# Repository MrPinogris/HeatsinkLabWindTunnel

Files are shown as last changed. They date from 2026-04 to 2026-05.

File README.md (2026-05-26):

# HeatsinkLab Wind Tunnel

ESP32-S3 based heatsink thermal characterisation platform. A ceramic heater drives the heatsink under test to a series of set-point temperatures while a controlled fan provides forced convection through the wind tunnel. All sensor data streams to a browser-based GUI; results are saved automatically as a CSV.

---

## System Architecture

```
┌──────────────────────────────────┐
│  Firmware (C++ / ESP32-S3)       │  src/  — stable, treat as black box
│  · PID heater + fan control      │
│  · MAX6675 thermocouple (SPI)    │
│  · INA226 power monitor (I²C)    │
│  · SDP510 diff. pressure (I²C)   │
│  · EZO-HUM humidity probe (I²C)  │
│  · Serial command interface      │
└────────────┬─────────────────────┘
             │ USB Serial 115 200 baud
┌────────────▼─────────────────────┐
│  Backend  (Python / FastAPI)     │  tools/web_gui/server.py
│  · WebSocket server :8765        │
│  · Telemetry parser              │
│  · CSV logger                    │
│  · Virtual MCU simulator         │
└────────────┬─────────────────────┘
             │ WebSocket
┌────────────▼─────────────────────┐
│  Frontend (HTML / JS / CSS)      │  tools/web_gui/static/index.html
│  · Chart.js real-time graphs     │
│  · PID tuning controls           │
│  · Tester workflow (automated)   │
│  · CSV export                    │
└──────────────────────────────────┘
```

---

## Hardware

### Component Summary

| Component | Part | Interface | I²C Address |
|---|---|---|---|
| MCU | ESP32-S3 DevKit-C1 | — | — |
| Temperature sensor | MAX6675 thermocouple module | SPI | — |
| Power monitor | INA226 (A0 → VCC) | I²C | 0x41 |
| Differential pressure | Sensirion SDP510 | I²C | 0x40 |
| Humidity probe | EZO-HUM (Atlas Scientific) | I²C | 0x6F |
| Heater switch | MOSFET module (PWM gate) | GPIO 4 | — |
| Fan PWM | MOSFET / driver module | GPIO 5 | — |
| Fan power cut-off | MOSFET module (digital gate) | GPIO 10 | — |

### ESP32-S3 Pin Assignments

| GPIO | Function | Notes |
|---|---|---|
| 4 | Heater MOSFET gate | PWM 500 Hz, 8-bit (0–255) |
| 5 | Fan PWM signal | PWM 500 Hz, 8-bit |
| 10 | Fan power MOSFET gate | HIGH = powered, LOW = fully off |
| 11 | MAX6675 SO (MISO) | SPI |
| 12 | MAX6675 CS | SPI |
| 13 | MAX6675 SCK | SPI |
| 15 | I²C SDA | Shared bus: INA226, SDP510, EZO-HUM |
| 16 | I²C SCL | Shared bus |

---

## Wiring

### Power Distribution

```
12 V Lab PSU (+) ─────┬──────────────────── Heater MOSFET IN+
                      └──────────────────── Fan MOSFET IN+
12 V Lab PSU (−) ─────┬──────────────────── Heater MOSFET IN−
                      ├──────────────────── Fan MOSFET IN−
                      └──────────────────── ESP32 GND (common)
```

### Heater Power Path

```
12 V (+) → Heater MOSFET IN+
           Heater MOSFET OUT+ → Heater element (+)
           Heater element (−) → INA226 IN+
                                INA226 IN−  → Heater MOSFET OUT−
12 V (−) → Heater MOSFET IN−  (common GND)

ESP GPIO 4  → Heater MOSFET signal
ESP GND     → Heater MOSFET signal GND
```

INA226 shunt is wired in series with the heater so it measures heater current directly.

### Fan Power Path

```
12 V (+) → Fan MOSFET (power cut-off) IN+
           Fan MOSFET OUT+ → Fan (+) / PWM driver IN+
12 V (−) → Fan MOSFET IN−  (common GND)

ESP GPIO 5  → Fan PWM signal
ESP GPIO 10 → Fan power MOSFET gate  (HIGH = fan enabled, LOW = fully off)
ESP GND     → Fan MOSFET signal GND
```

### MAX6675 Thermocouple (SPI)

| MAX6675 Pin | Connects to |
|---|---|
| VCC | ESP32 3.3 V |
| GND | ESP32 GND |
| SCK | GPIO 13 |
| CS  | GPIO 12 |
| SO  | GPIO 11 |

### INA226 Power Monitor (I²C, 0x41)

| INA226 Pin | Connects to |
|---|---|
| VCC | ESP32 3.3 V |
| GND | ESP32 GND |
| SDA | GPIO 15 |
| SCL | GPIO 16 |
| A0  | 3.3 V (sets address to 0x41) |
| A1  | GND |
| IN+ | Heater element output |
| IN− | Heater MOSFET drain |
| ALE | Not connected |

### Sensirion SDP510 Differential Pressure (I²C, 0x40)

| SDP510 Pin | Connects to |
|---|---|
| VCC | ESP32 3.3 V |
| GND | ESP32 GND |
| SDA | GPIO 15 (shared I²C bus) |
| SCL | GPIO 16 (shared I²C bus) |

Sensor is mounted across the wind tunnel to measure pressure drop (Pa) between inlet and outlet.

### EZO-HUM Humidity Probe (I²C, 0x6F)

| EZO-HUM Pin | Connects to |
|---|---|
| VCC (red) | ESP32 3.3 V |
| GND (black) | ESP32 GND |
| SDA (green) | GPIO 15 (shared I²C bus) |
| SCL (white) | GPIO 16 (shared I²C bus) |
| AUTO (blue) | Not connected |

> **First-time setup:** Factory default is UART mode (blinking green LED).
> Send `I2C,111\r` at 9600 baud over UART once, then power-cycle until LED is solid blue (I²C mode).

---

## Physical Assembly

See `docs/media/` for annotated photos of the physical build. Key assembly features:

- **Wind tunnel inlet** — Fan with a hexagonal (honeycomb) grid immediately downstream to break up turbulence and produce laminar airflow through the tunnel.
- **Fan guard** — A protective shield covers the fan face to prevent contact injury during operation.
- **Heater module** — Ceramic PTC heater element topped with a copper spreader plate. The thermocouple is inserted into a precision-drilled hole in the copper plate to measure the heatsink base temperature accurately. The heatsink under test clips onto the copper plate.
- **Dev board** — All MOSFET switching modules, the INA226, and the ESP32-S3 DevKit are mounted on the dev board. The connector row (left to right) carries: humidity sensor, differential pressure sensor, and fan motor.
- **Expansion** — One additional MOSFET module on the left of the fan motor connector provides the independent power cut-off for the fan (GPIO 10), allowing the fan to be fully de-energised for natural-convection tests.

---

## Flashing the Firmware

Requires [PlatformIO](https://platformio.org/) (VS Code extension or CLI).

```bash
pio run -t upload      # Build and flash to connected ESP32-S3
pio run                # Build only (no upload)
```

> The firmware source is under `src/` and is considered stable. Do not modify it without reviewing `CLAUDE.md` first.

---

## Web GUI

### Requirements

- Windows 10/11 (Linux/macOS also supported)
- Python 3.10 or newer

### Install & Run

```bash
cd tools/web_gui
pip install -r requirements.txt
python server.py
```

Browser opens automatically at **http://localhost:8765**.

**Quickstart (Windows):** double-click `tools/web_gui/start.bat` — installs dependencies and launches the server.

### Testing without hardware

Select **VIRTUAL** from the port dropdown to use the built-in firmware simulator. No ESP32 required.

---

## Control Modes

| Mode | Behaviour |
|---|---|
| AUTO | PID loop continuously drives heater PWM toward setpoint |
| MANUAL | Fixed PWM set directly by the `MANPWM` parameter |
| SMART | PID until stable (±0.5 °C for 8 s), then locks the equilibrium PWM — used for automated Tester mode |

---

## Serial Command Reference

Commands are sent from the backend to the ESP32 over USB serial (115 200 baud):

| Command | Range | Description |
|---|---|---|
| `SET KP <f>` | float | PID proportional gain |
| `SET KI <f>` | float | PID integral gain |
| `SET KD <f>` | float | PID derivative gain |
| `SET BIAS <f>` | −255 to 255 | PID output bias |
| `SET SPBIAS <f>` | float | Setpoint offset bias |
| `SET SP <f>` | −20 to 400 °C | Temperature setpoint |
| `SET ALPHA <f>` | 0.001 to 1.0 | EMA filter coefficient |
| `SET MAXSTEP <n>` | int | Maximum PWM change per cycle |
| `SET FAN <n>` | 0 to 100 | Fan speed % |
| `SET FANINV <0/1>` | 0 or 1 | Invert fan PWM polarity |
| `SET FANPWR <ON/OFF>` | ON / OFF | Fan power MOSFET enable |
| `SET MODE <m>` | AUTO/MANUAL/SMART | Control mode |
| `SET MANPWM <f>` | 0 to 255 | Manual PWM value |
| `SET RUN <ON/OFF>` | ON / OFF | Enable / disable heater |
| `GET` | — | Print current configuration |

All parameters are bounds-checked in firmware before acceptance.

---

## Telemetry Output

The firmware emits one telemetry line per control cycle over serial. Example fields:

```
Rawtemp <°C>  Temp: <°C>  Smooth: <°C>  PWM: <0-255>
P: <f>  I: <f>  D: <f>  OUT: <f>  BIAS: <f>  SPBIAS: <f>
SP: <°C>  EFFSP: <°C>  FAN: <%>  FANPWM: <raw>
MODE: <AUTO|MANUAL|SMART>  STATE: <PID|HOLD|MANUAL>
MANPWM: <f>  HOLDPWM: <f>  ENTPROG: <%>  EXTPROG: <%>  EABS: <°C>
RUN: <ON|OFF>  FANINV: <0|1>
V: <V>  I: <A>  W: <W>  EQPWM: <0-255>  FANPWR: <ON|OFF>
HUMIDITY: <%>  HUM_TEMP: <°C>
DELTA_P1: <Pa>  DELTA_P1F: <Pa>  DELTA_P2: <Pa>  DELTA_P2F: <Pa>
```

---

## CSV Schema

Raw telemetry is logged to `logs/serial_<timestamp>.csv`. Schema version 4.

```
timestamp_iso, elapsed_s, raw_temp_c, temp_filtered_c, temp_smooth_c,
pwm, p_term, i_term, d_term, pid_out, pid_bias, setpoint_bias_c,
setpoint_c, effective_setpoint_c, fan_speed_pct, fan_pwm_raw, fan_power,
mode, state, manual_pwm_cmd, hold_pwm, enter_progress_pct,
exit_progress_pct, abs_error_c, run_state, fan_inverted,
vin, iin, pin, eq_pwm,
delta_p1, delta_p1f, delta_p2, delta_p2f,
humidity_pct, hum_temp_c,
event
```

Results CSV (one row per test temperature):

```
timestamp, run_id, heatsink_id, sp_temp, temp, amb_temp,
pwm_heater, fan_cmd, fan_pwm, airspeed, delta_p1, delta_p2,
humidity_pct, vin, iin, pin, mode, state, event
```

---

## Future Sensors

The system is designed for zero-disruption sensor additions. The `ExtSensorRegistry` in firmware provides named slots; the backend `TELEM_RE` regex accepts new named fields without breaking the existing parser.

| Sensor | CSV Fields | Status |
|---|---|---|
| Airspeed / anemometer | `airspeed` (m/s) | Planned — hardware not yet wired |
| Differential pressure (second port) | `delta_p2`, `delta_p2f` (Pa) | Parser ready; physical port mapped to 0 |
| Ambient humidity (additional) | `humidity_pct` | EZO-HUM implemented; Sensirion variant planned |

See `CLAUDE.md` for the 4-step pattern to add any new sensor without breaking existing data flows.

---

## Repository Structure

```
HeatsinkLabWindTunnel/
├── src/                        Firmware (C++ / PlatformIO)
│   ├── main.cpp                Setup, loop, control FSM
│   ├── PIDController.cpp/h     PID controller
│   ├── SensorManager.cpp/h     Sensor reads, EMA, glitch reject
│   ├── SerialProtocol.cpp/h    Serial command handler + telemetry emitter
│   ├── ExtSensorRegistry.cpp/h Named slot registry for future sensors
│   └── SystemState.h           Shared state struct + ControlMode enum
├── tools/web_gui/
│   ├── server.py               FastAPI backend + WebSocket + CSV logger
│   ├── static/index.html       Single-file browser GUI
│   ├── requirements.txt        Python dependencies
│   ├── start.bat               Windows one-click launcher
│   └── MANUAL.md               User-facing operating manual
├── docs/
│   ├── hardware.md             Detailed hardware reference (this thesis)
│   ├── Connections.txt         Raw wiring connection list
│   ├── media/                  Annotated build photographs
│   └── Todo.md                 Development task list
├── notes/
│   └── Ideas.md                Feature backlog with prioritisation scores
├── platformio.ini              PlatformIO build configuration
└── CLAUDE.md                   AI agent working instructions
```

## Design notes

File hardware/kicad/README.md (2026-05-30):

# HeatsinkLab Carrier Board — KiCad Project

Open `heatsinklab.kicad_pro` in KiCad 8.

## Files
- `heatsinklab.kicad_pro` — project settings and net classes
- `heatsinklab.kicad_sch` — full schematic
- `heatsinklab.kicad_pcb` — PCB layout (160 mm × 120 mm)

## After opening in KiCad

1. **Schematic**: Run *Tools → Update PCB from Schematic* to sync any edits.
2. **PCB**: Run the DRC, then route the remaining ratsnest connections.  
   Use the **Zone** tool (copper pour) for the GND plane.
3. **Footprints**: All standard KiCad 8 library footprints — no custom libs needed.

## Net classes (already configured)

| Class | Track width | Applies to |
|---|---|---|
| Default | 0.25 mm | GPIO signals, I2C, SPI |
| Power | 2.0 mm | +12V, GND, HEATER*, FAN_PWR* |

## Heater path warning

The +12V → Q1 → INA226 → J2 trace carries up to ~3–5 A.  
Route it as a **wide copper pour zone** (≥5 mm) or solder wire on top of the copper tape.

## Board dimensions

160 mm × 120 mm, 4× M3 mounting holes at corners.

## Component placement (as placed in PCB file)

| Ref | Component | XY (mm) |
|-----|---|---|
| J1  | PWR_IN 2p | 12, 15 |
| J2  | HEATER_OUT 2p | 12, 35 |
| J4  | FAN_OUT 2p | 12, 50 |
| J5  | FAN_PWM 2p | 12, 65 |
| J6  | THERMO 5p | 148, 15 |
| J7  | INA226 4p | 148, 40 |
| J8  | SDP510 4p | 148, 60 |
| J9  | EZO-HUM 4p | 148, 80 |
| J10 | EXT1 4p | 148, 100 |
| Q1  | IRLZ44N Heater | 50, 30 |
| Q2  | IRLZ44N Fan | 50, 55 |
| R1  | 4.7k SDA pull-up | 120, 38 |
| R2  | 4.7k SCL pull-up | 120, 48 |
| R3  | 10k Q1 gate pull-down | 35, 30 |
| R4  | 10k Q2 gate pull-down | 35, 55 |
| U1  | ESP32-S3 dev board header | 80, 60 |

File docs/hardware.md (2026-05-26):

# HeatsinkLab Wind Tunnel — Hardware Reference

This document is the complete hardware reference for the HeatsinkLab Wind Tunnel platform. It covers all components, connections, I²C bus layout, power distribution, and physical assembly details.

For photos of the physical build see `docs/media/`.

---

## Bill of Materials

| Qty | Component | Part / Variant | Role |
|---|---|---|---|
| 1 | Microcontroller | ESP32-S3 DevKit-C1 | Main controller, USB serial, WiFi (reserved) |
| 1 | Thermocouple module | MAX6675 breakout (K-type) | Heatsink base temperature measurement |
| 1 | Thermocouple | K-type, 1 m, with stainless probe | Inserted into copper spreader plate |
| 1 | Power monitor | INA226 breakout (A0 → VCC, addr 0x41) | Heater current, voltage, and power measurement |
| 1 | Differential pressure sensor | Sensirion SDP510 (I²C, addr 0x40) | Airflow differential pressure across tunnel |
| 1 | Humidity probe | Atlas Scientific EZO-HUM (I²C, addr 0x6F) | Ambient relative humidity and temperature |
| 2 | MOSFET switch module | Generic PWM MOSFET module (e.g. BTS7960 or IRF520) | Heater power switching (PWM), Fan power cut-off |
| 1 | Fan | 12 V DC brushless fan with PWM input | Forced convection through wind tunnel |
| 1 | Ceramic PTC heater | 12 V ceramic heater plate | Heat source for heatsink under test |
| 1 | Copper spreader plate | Custom machined, with thermocouple hole | Uniform heat distribution onto heatsink |
| 1 | Hexagonal grid / honeycomb | 3D printed or purchased | Laminar flow conditioning at fan inlet |
| 1 | Fan guard / shield | 3D printed or purchased | User safety — prevents finger contact with fan |
| 1 | Lab power supply | 12 V DC, ≥ 5 A | Power for heater and fan |
| — | Dev board / perfboard | Custom | Mounts MOSFET modules, ESP32, and connectors |

---

## ESP32-S3 Pin Assignments

| GPIO | Function | Direction | Notes |
|---|---|---|---|
| 4 | Heater MOSFET gate | Output | PWM 500 Hz, 8-bit (0–255). LEDC channel. |
| 5 | Fan PWM signal | Output | PWM 500 Hz, 8-bit. LEDC channel. Fan driver PWM input. |
| 10 | Fan power MOSFET gate | Output | HIGH = fan powered, LOW = fan fully off. Digital only. |
| 11 | MAX6675 SO (MISO) | Input | SPI — thermocouple serial data |
| 12 | MAX6675 CS | Output | SPI — chip select (active LOW) |
| 13 | MAX6675 SCK | Output | SPI — clock |
| 15 | I²C SDA | Bidirectional | Shared bus: INA226, SDP510, EZO-HUM |
| 16 | I²C SCL | Output | Shared bus |

---

## I²C Bus Map

All three I²C sensors share GPIO 15 (SDA) and GPIO 16 (SCL). Address conflicts are avoided by hardware configuration:

| Device | Address | How set |
|---|---|---|
| INA226 power monitor | 0x41 | A0 pin wired to VCC (≠ default 0x40) |
| Sensirion SDP510 pressure | 0x40 | Fixed in silicon — not configurable |
| EZO-HUM humidity probe | 0x6F | Factory default I²C address (after mode switch) |

> **Note:** `Wire.setTimeOut(200)` is set in firmware. The SDP510 uses I²C clock-stretching during measurement (up to 80 ms); the extended timeout prevents false read errors.

---

## Power Distribution

```
12 V Lab PSU (+) ────┬──── Heater MOSFET IN+
                     └──── Fan MOSFET (power cut-off) IN+

12 V Lab PSU (−) ────┬──── Heater MOSFET IN−
                     ├──── Fan MOSFET IN−
                     └──── ESP32 GND  ←── common ground reference
```

### Heater Circuit (PWM controlled via GPIO 4)

```
12 V (+) → Heater MOSFET IN+
           Heater MOSFET OUT+ ──→ Heater element (+)
           Heater element (−) ──→ INA226 IN+  [shunt resistor]
                                  INA226 IN−  ──→ Heater MOSFET OUT−
12 V (−) → Heater MOSFET IN−  (common GND)

GPIO 4  → Heater MOSFET signal
ESP GND → Heater MOSFET signal GND
```

The INA226 shunt is placed in series with the heater element, measuring current flow through it directly.

### Fan Circuit (PWM via GPIO 5, power enable via GPIO 10)

```
12 V (+) → Fan power MOSFET IN+
           Fan power MOSFET OUT+ ──→ Fan supply (+)
12 V (−) → Fan power MOSFET IN−  (common GND)

GPIO 5  → Fan PWM signal (speed control)
GPIO 10 → Fan power MOSFET gate  (HIGH = on, LOW = fully off)
ESP GND → Fan MOSFET signal GND
```

GPIO 10 allows the fan to be completely de-energised for natural-convection tests, regardless of the PWM duty cycle.

---

## Sensor Wiring

### MAX6675 Thermocouple Module

| MAX6675 Pin | Wire colour (typical) | Connects to |
|---|---|---|
| VCC | Red | ESP32 3.3 V |
| GND | Black | ESP32 GND |
| SCK | Yellow | GPIO 13 |
| CS  | Orange | GPIO 12 |
| SO  | Green | GPIO 11 |

The K-type thermocouple probe tip is inserted into the precision hole in the copper spreader plate. The copper plate sits on top of the ceramic heater; the heatsink under test is clamped onto the top face of the copper plate.

### INA226 Power Monitor

| INA226 Pin | Connects to | Notes |
|---|---|---|
| VCC | ESP32 3.3 V | |
| GND | ESP32 GND | |
| SDA | GPIO 15 | Shared I²C bus |
| SCL | GPIO 16 | Shared I²C bus |
| A0  | ESP32 3.3 V | Sets address to 0x41 |
| A1  | ESP32 GND | |
| IN+ | Heater element output | High side of shunt |
| IN− | Heater MOSFET drain | Low side of shunt |
| ALE | Not connected | |
| VBS | Not connected | |

Firmware configuration: 1024-sample averaging, 8.3 ms conversion time per channel, calibrated for the installed shunt resistor value.

### Sensirion SDP510 Differential Pressure

| SDP510 Pin | Connects to | Notes |
|---|---|---|
| VDD | ESP32 3.3 V | |
| GND | ESP32 GND | |
| SDA | GPIO 15 | Shared I²C bus |
| SCL | GPIO 16 | Shared I²C bus |

The sensor is mounted so that Port 1 faces the upstream side (fan outlet) and Port 2 faces downstream (heatsink outlet) of the tunnel, measuring the net pressure drop. Range: ±500 Pa. Scale factor: 60 counts/Pa.

### EZO-HUM Humidity Probe (Atlas Scientific)

| EZO-HUM Pin | Wire colour | Connects to | Notes |
|---|---|---|---|
| VCC | Red | ESP32 3.3 V | |
| GND | Black | ESP32 GND | |
| SDA | Green | GPIO 15 | Shared I²C bus |
| SCL | White | GPIO 16 | Shared I²C bus |
| AUTO | Blue | Not connected | Leave floating |

> **One-time I²C mode activation:** Factory default is UART mode (LED blinks green).
> Connect to a USB-UART adapter, open a serial terminal at 9600 baud, send `I2C,111\r`,
> then power-cycle. The LED turns solid blue confirming I²C mode. Address 0x6F.

---

## Connector Layout on Dev Board

From the Connections.txt wiring document (left to right on the sensor connector rail):

```
[ Humidity sensor ]  [ Pressure sensor ]  [ Fan motor ]
      Left                 Middle              Right
```

Between the pressure sensor connector and the fan motor connector there is an additional MOSFET module for the fan power cut-off (GPIO 10). This module is not shown in all photos.

---

## Physical Assembly

### Wind Tunnel

- Fan is mounted at the inlet end of the tunnel
- A hexagonal (honeycomb) grid is placed directly in front of the fan blades to break up turbulence and produce laminar airflow
- A protective shield covers the fan face on the outside of the tunnel to prevent accidental contact

Photos in `docs/media/`:
- `Fan at beginning of windtunnel with hexagonal grid in front to get laminar windflow.HEIC`
- `fan at beginning of windtunnel and the protective outside shield visible (protection for user).HEIC`
- `fan at beginning of windtunnel seen from inside of the tunnel and the hexgrid also visible.HEIC`
- `full windtunnel (incomplete) no side panel attached yet.HEIC`

### Heater Module

The heater module is a layered assembly (bottom to top):
1. **Ceramic PTC heater plate** — 12 V, controlled via MOSFET
2. **Copper spreader plate** — sits directly on top of the ceramic heater, machined with a small blind hole in one edge for the thermocouple probe tip
3. **Thermocouple** — K-type probe inserted into the copper plate hole; measures the temperature at the base of the heatsink
4. **Heatsink under test** — clamped onto the top face of the copper plate

Photos in `docs/media/`:
- `heater module with only ceramic heater and ceramic heater visible.HEIC`
- `heater module with ceramic heater visible and the copper plate placed vertically to show where the hole for thermocouple when place horizontally.HEIC`
- `heater module where the copper plate that is on top of the ceramic heater is visible (thermocouple is placed inside this copper) bit no heatsinc attached.HEIC`
- `heater module but only copper plate visible and partially sticking out to show the thermocouple placed inside.HEIC`
- `fulle heater module without thermocouple inside yet.HEIC`
- `full heater module with heatsinc visible and thermocouple inside.HEIC`
- `Full heater module with heatsinc visible and thermocouple inside 2.HEIC`
- `Thermocouple that goes in the Copper plate of the heater module.HEIC`

### Dev Board

- ESP32-S3 DevKit-C1 mounted centrally
- Two MOSFET switch modules: one for heater (PWM), one for fan power cut-off (digital)
- INA226 breakout mounted near the heater MOSFET (shunt leads kept short)
- Sensor connector rail (left to right): humidity, pressure, fan motor

Photos in `docs/media/`:
- `Full devboard with esp(unfinished) missing 1 more mossfet module to the left for the power cutoff to fan.HEIC`
- `Full devboard without esp(unfinished) missing 1 more mossfet module to the left for the power cutoff to fan.HEIC`
- `power connector and PWM out module to Heateplate and part of USBC connection from ESP to PC.HEIC`
- `Left humidity sensor connector midle Preassure sensor connector right Motor connector (between P1 and M1 there's now a Mossfet module now that can cut power to M1 also but this is not in pic).HEIC`

### Sensors

Photos in `docs/media/`:
- `humididty sensor.HEIC` — EZO-HUM humidity probe
- `Pressure diff Sensor.HEIC` — Sensirion SDP510 differential pressure sensor

---

## Safety Notes

- Maximum operating temperature: 400 °C (firmware setpoint ceiling). Lab usage typically 40–120 °C.
- The ceramic heater element stays energised until `SET RUN OFF` is sent or the GUI disconnects. Never leave the system unattended with `RUN: ON`.
- If the thermocouple reads 0 °C, NaN, or produces a stuck-sensor fault, the firmware cuts heater power immediately.
- The INA226 must be wired and responding before starting a test. If power reads 0, R_th results will be invalid (NaN or ∞).
- Common GND between the lab PSU and the ESP32 is required for MOSFET gate signals to work correctly.

---

## Planned Hardware Additions

| Sensor | Interface | Purpose | Status |
|---|---|---|---|
| Second SDP510 port or anemometer | Analog / I²C | Direct airspeed measurement (m/s) | Not yet wired |
| Second differential pressure channel | I²C | Redundant or two-point pressure | Parser ready, hardware pending |
| Additional temperature sensors | SPI (additional MAX6675 slots) | Inlet / outlet air temperature | Not yet wired |

See `notes/Ideas.md` for feature backlog and prioritisation.

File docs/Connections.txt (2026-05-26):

## General

12V supplied via lab power supply
GND LAB connected to GND ESP

### HEATER POWER
12V to mossfet module(HEATER) IN+ 
GND to mossfet module(HEATER) IN-
mossfet module(HEATER) OUT- to Current sensor INA226 I-
Current sensor INA226 I- to Heater
mossfet module(HEATER) OUt+ to Heater
ESP PIN 4 to mossfet module(heater) Signal
GND LAB POWER to mossfet module(heater) Signal

### Fan power
12V to mossfet module(FAN) IN+ 
GND to mossfet module(FAN) IN-
ESP PIN 5 to FAN PWM
ESP PIN 10 TO MOSSFET module(fan) signal
GND LAB POWER TO MOSSFET module(fan) signal

THERMOCOUPLE MAX 6675
GND ESP to GND Thermocouple module
VCC ESP to VCC Thermocouple module
ESP pin 13 to SCK Thermocouple module
ESP pin 12 to CS Thermocouple module
ESP pin 11 to SO Thermocouple module

Powersensor INA226 (I²C address: 0x41)
ESP pin 15 to SDA INA226
ESP pin 16 to SCL INA226
VCC ESP to VCC INA226
GND ESP to GND INA226
ALE INA226 NC
VBS INA226 NC

Pressure Sensor sensirion (I²C address: 0x40)
ESP pin 15 to SDA Pressure sensor
ESP pin 16 to SCL Pressure sensor
VCC ESP to VCC Pressure sensor
GND ESP to GND Pressure sensor

Humidity sensor sensirion (I²C address: 0xF6)
ESP pin 15 to SDA Humidity sensor
ESP pin 16 to SCL Humidity sensor
VCC ESP to VCC Humidity sensor
GND ESP to GND Humidity sensor

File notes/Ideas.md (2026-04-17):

## HeatsinkLab Wind Tunnel — Feature Backlog

---

## End Goal (Student Workflow)

The system must deliver this exact experience for every student:

```
1. Plug ESP32 into lab PC via USB
2. Open GUI (double-click start.bat)
3. Follow guided wizard → select port → click Connect → sensors verified automatically
4. Type heatsink ID (e.g. "HS-03-copper-fin")
5. Press ONE button: "Start Test"
6. Wait — temperatures step automatically, soak, record, step again
7. Results CSV downloads automatically when test finishes
8. Remove heatsink, insert next one, repeat from step 4
```

Students must never need to know what PID is, what a COM port is (beyond selecting from a list), or manually configure temperatures.

---

## Target CSV Schema (Final)

```text
timestamp, run_id, heatsink_id, sp_temp, temp, amb_temp, pwm_heater, fan_cmd, fan_pwm,
airspeed, delta_p1, delta_p2, humidity_pct, vin, iin, pin, mode, state, event
```

Fields `airspeed`, `delta_p1`, `delta_p2`, `humidity_pct` are reserved placeholders — they will be populated once the corresponding hardware sensors are connected. Preserve them in the schema even before the sensors exist.

---

## Prioritisation Framework

```
Score = 2×Importance + 2×Necessity + 2×Dependency − Effort

Importance  (1–5): impact on heatsink-comparison quality
Necessity   (1–5): required for a usable student lab workflow
Dependency  (0/1): blocks other high-value work
Effort      (1–5): engineering cost / complexity
```

Sort by highest Score first.

---

## Backlog Template

```text
Title:
Goal:
Category: [GUI | Backend | Firmware | Data | Safety | Analysis | Reporting | Build]

Importance (1-5):
Necessity (1-5):
Dependency (0/1):
Effort (1-5):
Score:

Dependencies:
Acceptance Criteria:
- ...

Notes:
```

---

## Backlog (sorted by score, highest first)

---

```text
Title: Safety Layer
Goal: Configurable max-temperature cutoff with a persistent SAFE / RUNNING / FAULT status indicator visible at all times
Category: Safety / GUI / Backend

Importance (1-5): 5
Necessity (1-5): 5
Dependency (0/1): 1
Effort (1-5): 4
Score: 19

Dependencies: none (software-side status indicator can be done now; hardware watchdog MCU is a separate physical build)
Acceptance Criteria:
- GUI shows a persistent status badge at the top: SAFE (grey), RUNNING (green), FAULT (red)
- FAULT is triggered by: temperature exceeding configurable limit, thermocouple stuck, INA226 absent, test stalled indefinitely
- On FAULT: GUI automatically sends SET RUN OFF and blocks further test start until acknowledged
- Instructor can configure max allowed temperature (default 120 C for lab safety)
- Each fault shows a fault code with a human-readable explanation (e.g. "FAULT F02: Thermocouple stuck at 25.0 C for 15s")
- Student can reset FAULT only after manually confirming the issue is resolved (confirm dialog)

Notes: The hardware safety watchdog (separate MCU with independent power) is a physical build item outside this software scope.
This item covers the software-side safety indicator and automatic shutdown logic in server.py and index.html.
```

---

```text
Title: Post-Test Auto Shutdown
Goal: Automatically cut heater power when a test finishes — heater must never stay on unattended
Category: Backend / GUI

Importance (1-5): 5
Necessity (1-5): 5
Dependency (0/1): 0
Effort (1-5): 1
Score: 17

Dependencies: none
Acceptance Criteria:
- When the last temperature step completes its soak and results are recorded: send SET RUN OFF automatically
- Set fan to a low idle speed (e.g. 20%) for 60s cool-down, then SET FAN 0
- Log a TEST_COMPLETE event in the raw CSV
- GUI shows "Test complete — heater off" status message prominently
- If test is manually stopped mid-run: also send SET RUN OFF immediately
- Auto-shutdown also triggers if a FAULT is detected during a test

Notes: Safety-critical. The heater must never remain on after a test finishes.
Currently the firmware stays in RUN ON state indefinitely after a test unless the user manually clicks a button.
This is a one-line fix in the test completion handler in index.html.
```

---

```text
Title: Temperature Range / Batch Entry
Goal: Let students specify a temperature range (start, stop, step) instead of adding temperatures one-by-one
Category: GUI

Importance (1-5): 4
Necessity (1-5): 5
Dependency (0/1): 0
Effort (1-5): 2
Score: 16

Dependencies: none
Acceptance Criteria:
- Tester panel has a "Range" row: Start degC, Stop degC, Step degC with a "Generate List" button
- Clicking Generate populates the temperature list automatically (e.g. 40, 50, 60, 70, 80 C)
- Also support pasting a comma-separated list directly (e.g. "40, 55, 70, 85")
- Generated list is editable — students can remove individual entries before starting
- One-by-one Add button remains available as a fallback
- Default values shown on first open: Start 40, Stop 80, Step 10 (covers typical lab range)

Notes: Currently students must add every temperature individually by typing and clicking Add.
For a 7-point test this is 7x type + click. This is the biggest friction point in the current Tester mode.
```

---

```text
Title: Guided Connection Wizard
Goal: Walk students through device connection with step-by-step instructions instead of a bare port dropdown
Category: GUI / Backend

Importance (1-5): 4
Necessity (1-5): 4
Dependency (0/1): 1
Effort (1-5): 3
Score: 15

Dependencies: Sensor Health Check (merge as last wizard step)
Acceptance Criteria:
- On first open (or when not connected): a wizard panel guides the student:
    Step 1 — "Plug the USB cable into the ESP32 and into this PC" [Refresh ports] shows detected ports
    Step 2 — "Select the COM port from the list and click Connect"
    Step 3 — "Checking device..." with animated spinner during 2.5s handshake (not a silent wait)
    Step 4 — "Device connected" or "Connection failed: try a different USB cable or port"
- If handshake fails: show actionable message ("Check USB cable, check Device Manager, try replugging")
- After connect: show sensor health check before allowing test start (see Sensor Health Check item)
- Wizard can be dismissed by experienced users who already know what to do

Notes: Currently there is zero guidance. Students see a bare COM port dropdown and a Connect button.
The 2.5s handshake is completely silent — no indication anything is happening.
This is the first thing new students encounter and currently causes the most confusion.
```

---

```text
Title: Airflow Telemetry Integration
Goal: Log and display airspeed and differential pressure once hardware sensors are connected
Category: Backend / GUI / Data

Importance (1-5): 5
Necessity (1-5): 4
Dependency (0/1): 1
Effort (1-5): 3
Score: 15

Dependencies: Hardware sensor wiring + firmware update to output airspeed/delta_p in telemetry
Acceptance Criteria:
- server.py TELEM_RE parses airspeed (m/s) and delta_p1, delta_p2 (Pa) from telemetry
- Live values shown in GUI sidebar
- Fields logged to raw CSV (schema_version bumped)
- Results CSV includes avg airspeed and avg delta_p per test point
- If sensor is absent (value = 0 or NaN): show "—" in display, do not block test

Notes: Follow the 4-step sensor extension pattern in CLAUDE.md.
The firmware output format must be updated when sensors are physically wired.
CSV schema already reserves these column names — do not rename them.
This item requires firmware changes — confirm with user before starting.
```

---

```text
Title: Auto Result Download on Test Completion
Goal: Automatically save/download both CSVs when a test finishes — no manual button clicks required
Category: GUI / Backend

Importance (1-5): 4
Necessity (1-5): 4
Dependency (0/1): 0
Effort (1-5): 2
Score: 14

Dependencies: Post-Test Auto Shutdown (should trigger at the same moment)
Acceptance Criteria:
- When test completes: Results CSV is automatically downloaded to the browser Downloads folder
- Raw CSV is already being written server-side — ensure it is finalized (flush + close) on test end
- GUI shows "Results saved: heatsink_results_HS-01_2026-03-29.csv" confirmation message
- Student does not need to click any download button
- If browser blocks auto-download: show a prominent "Download Results" button as fallback
- Raw CSV filename includes heatsink ID and timestamp

Notes: Currently students must click two separate download buttons after the test.
Many will close the browser tab immediately, losing the in-memory Results table.
```

---

```text
Title: Startup Sensor Health Check
Goal: Verify all required sensors are responding correctly right after connection, before allowing a test to start
Category: GUI / Backend

Importance (1-5): 4
Necessity (1-5): 4
Dependency (0/1): 0
Effort (1-5): 3
Score: 13

Dependencies: Guided Connection Wizard (health check becomes the final step)
Acceptance Criteria:
- After successful handshake: backend reads 3 telemetry frames and checks:
    Thermocouple: temperature is non-zero, not stuck, and in plausible range (15–45 C at room temp)
    INA226: voltage reading is non-zero (confirms power monitoring is active)
- GUI shows a sensor checklist:
    GREEN  Thermocouple: 23.4 C OK
    GREEN  Power monitor: 12.1V OK
    RED    Power monitor: 0V — check INA226 wiring
- Start Test button is disabled if any required sensor is RED
- Optional sensors (airspeed, pressure, humidity) show YELLOW "not connected" — test still allowed
- Student sees clear fix instructions for each failed check

Notes: Without INA226 power readings the R_th calculation produces invalid results (division near zero).
Currently the system silently produces NaN or infinite R_th if INA226 is not connected.
```

---

```text
Title: Dual-File Release Build
Goal: A single installer for the GUI and a pre-compiled firmware binary for lab technicians with no dev tools
Category: Build

Importance (1-5): 3
Necessity (1-5): 5
Dependency (0/1): 1
Effort (1-5): 4
Score: 13

Dependencies: all core features must be stable before packaging
Acceptance Criteria:
- GUI installer: single .exe or .bat that installs Python dependencies and creates a desktop shortcut
- Firmware binary: pre-built .bin file that can be flashed via esptool (no PlatformIO needed)
- Clear README for lab technician: "Run installer, plug in ESP32, run flash_firmware.bat"
- Version number embedded in GUI footer and firmware CFG output so mismatches are detectable

Notes: End goal is that a lab technician with no programming knowledge can set up the entire system.
Firmware binary also allows re-flashing a corrupted or replaced ESP32 without a dev environment.
```

---

```text
Title: Heatsink ID Input
Goal: Let students label each test with a heatsink identifier so result files are self-documenting
Category: GUI / Data

Importance (1-5): 3
Necessity (1-5): 4
Dependency (0/1): 0
Effort (1-5): 2
Score: 12

Dependencies: none
Acceptance Criteria:
- Tester panel has a "Heatsink ID" text field above the Start button (e.g. "HS-01-copper-fin")
- ID is included in:
    Results CSV filename: heatsink_results_HS-01_2026-03-29T143022.csv
    Results CSV header row
    Raw CSV filename: serial_HS-01_2026-03-29T143022.csv
- If field is empty: warn student before allowing test start ("Please enter a heatsink ID")
- ID is remembered until manually cleared (so student doesn't retype for re-runs of the same heatsink)

Notes: Currently all result files have generic timestamped names.
Students have no way to tell which file belongs to which heatsink without opening them.
```

---

```text
Title: Experiment Presets
Goal: Save and load full test configurations (temperature list, fan speed, soak time) with a name
Category: GUI

Importance (1-5): 3
Necessity (1-5): 3
Dependency (0/1): 0
Effort (1-5): 2
Score: 8

Dependencies: Temperature Range Entry recommended first
Acceptance Criteria:
- "Save Preset" button stores current test config (temps, fan %, soak time) under a user-chosen name
- "Load Preset" dropdown fills all fields instantly
- Presets persisted in browser localStorage (no server-side storage needed)
- Default presets shipped: "Lab Standard 40-80 step 10", "Quick 3-point", "Natural Convection"
- Can delete a custom preset

Notes: Useful for instructors who want to standardise the test procedure across student groups.
Reduces setup time when running the same test repeatedly on different heatsinks.
```

---

```text
Title: Tooltips
Goal: Show brief plain-language explanations when hovering over controls and metric readouts
Category: GUI

Importance (1-5): 3
Necessity (1-5): 3
Dependency (0/1): 0
Effort (1-5): 1
Score: 8

Dependencies: none
Acceptance Criteria:
- All buttons, sliders, and metric readouts have a tooltip on hover
- Written in plain language — no engineering jargon
- Examples:
    Setpoint: "Target temperature in °C that the heater will try to reach"
    R_th: "Thermal resistance — how well this heatsink transfers heat. Lower is better."
    EqPWM: "Heater power at steady state (0–255). Lower means less power needed = better heatsink."
    Fan %: "Cooling fan speed. 0 = no forced airflow. 100 = maximum airflow."
- Tooltips updated as new features are added

Notes: Students have no PID background. Every unexplained number causes confusion and instructor questions.
```

---

```text
Title: In-App User Manual
Goal: Built-in help panel explaining all features and how to interpret results, available offline
Category: GUI

Importance (1-5): 2
Necessity (1-5): 4
Dependency (0/1): 0
Effort (1-5): 2
Score: 8

Dependencies: tooltips recommended first
Acceptance Criteria:
- A help button opens a panel or modal with the full user manual embedded in the page
- Sections: Getting Started, Running a Test, Understanding Results, Troubleshooting
- Explains R_th, k, EqPWM in plain language with typical example values
- Explains how to import the CSV into Excel using the Power Query formula (see CSV Export Customisation item)
- Available offline (embedded in index.html, not an external link)
- Current MANUAL.md content migrated here and kept in sync

Notes: MANUAL.md currently exists as a standalone file that students are unlikely to find.
Embedding it in the GUI ensures it is always one click away.
```

---

```text
Title: Graph Cursor / Probe Tool
Goal: Allow students to read exact values at any point in time on the live graph
Category: GUI

Importance (1-5): 3
Necessity (1-5): 2
Dependency (0/1): 0
Effort (1-5): 1
Score: 7

Dependencies: none
Acceptance Criteria:
- Cursor mode toggled on/off with a button
- Cursor slides along the time axis as mouse moves over the graph
- Tooltip shows all active series values at the cursor position
- Delta mode: click two points to see delta-T, delta-PWM, delta-time between them
- Does not interfere with normal chart pan/zoom

Notes: Useful for students reading values at specific moments (e.g. exactly when HOLD state was entered).
Low effort — Chart.js has crosshair plugin support built in.
```

---

```text
Title: CSV Export Customisation
Goal: Let users choose which columns to include in the exported CSV before downloading
Category: GUI / Data

Importance (1-5): 3
Necessity (1-5): 2
Dependency (0/1): 0
Effort (1-5): 2
Score: 6

Dependencies: none
Acceptance Criteria:
- When triggering CSV download: show a column-selection panel with checkboxes
- Checkboxes grouped by category: Temperature, PID Terms, Fan, Power, Metadata, Future Sensors
- Default selection: columns most relevant for student lab analysis (exclude raw PID internals)
- "Select all" and "Reset to default" buttons
- Companion .txt file with the matching Power Query formula is included in the download

Power Query formula (all current + future columns):
= Table.TransformColumnTypes(
    #"Promoted Headers",
    {
        {"timestamp_iso", type datetimezone},
        {"elapsed_s", type number},
        {"raw_temp_c", type number},
        {"temp_filtered_c", type number},
        {"temp_smooth_c", type number},
        {"pwm", Int64.Type},
        {"p_term", type number},
        {"i_term", type number},
        {"d_term", type number},
        {"pid_out", type number},
        {"pid_bias", type number},
        {"setpoint_bias_c", type number},
        {"setpoint_c", type number},
        {"effective_setpoint_c", type number},
        {"fan_speed_pct", type number},
        {"fan_pwm_raw", Int64.Type},
        {"mode", type text},
        {"state", type text},
        {"manual_pwm_cmd", type number},
        {"hold_pwm", type number},
        {"enter_progress_pct", type number},
        {"exit_progress_pct", type number},
        {"abs_error_c", type number},
        {"run_state", type text},
        {"fan_inverted", type number},
        {"vin", type number},
        {"iin", type number},
        {"pin", type number},
        {"airspeed", type number},
        {"delta_p1", type number},
        {"delta_p2", type number},
        {"humidity_pct", type number},
        {"hum_temp_c", type number}
    },
    "en-US"
)

Notes: Lower priority than the core workflow features.
Students at this stage don't need column selection — the full CSV is acceptable.
The Power Query formula above must be updated each time a new sensor column is added (bump schema_version too).
```

---

```text
Title: Closed-Loop Fan Airspeed Control
Goal: Control fan speed by feedback to maintain a target airspeed rather than a fixed PWM percentage
Category: Backend / Firmware

Importance (1-5): 4
Necessity (1-5): 3
Dependency (0/1): 0
Effort (1-5): 4
Score: 6

Dependencies: Airspeed sensor hardware + Airflow Telemetry Integration
Acceptance Criteria:
- GUI has a "Target airspeed (m/s)" input in the Tester panel alongside fan %
- Backend runs a simple feedback loop: adjust fan PWM until measured airspeed matches target
- Enables fair heatsink comparison: identical airspeed for all heatsinks tested
- Manual fan % control remains as fallback
- Results CSV records actual measured airspeed per test step, not just commanded fan %

Notes: Requires both software changes AND the airspeed sensor to be physically connected.
Deprioritised until airspeed hardware arrives.
```

---

```text
Title: Humidity and Ambient Conditions Logging
Goal: Log ambient humidity per test point for improved experiment repeatability
Category: Backend / Data

Importance (1-5): 3
Necessity (1-5): 2
Dependency (0/1): 0
Effort (1-5): 2
Score: 6

Dependencies: Humidity sensor hardware (e.g. SHT31 on I2C) + firmware update
Acceptance Criteria:
- Follow the 4-step sensor extension pattern in CLAUDE.md
- server.py parses humidity_pct from telemetry, broadcasts in telemetry message
- Field added to CSV_FIELDS (schema_version bumped)
- Shown in GUI sidebar
- Results CSV includes avg humidity per test point
- If sensor absent: field shows dash, test not blocked

Notes: Humidity affects air density and thus heat transfer.
Logging it enables students to compare results across different days and conditions.
Deprioritised until sensor hardware arrives.
```

---

```text
Title: Expert / Instructor Mode
Goal: Toggle between a simplified student view and a full-featured expert view
Category: GUI

Importance (1-5): 2
Necessity (1-5): 2
Dependency (0/1): 0
Effort (1-5): 3
Score: 5

Dependencies: none
Acceptance Criteria:
- Toggle between Student mode (test controls only) and Expert mode (all PID tuning, manual PWM, raw telemetry)
- GUI remembers last mode in localStorage
- In Student mode: PID sliders, manual PWM, bias inputs hidden
- In Expert mode: everything visible, same as current GUI
- Instructors can optionally lock mode so students cannot switch to Expert

Notes: The current GUI shows PID tuning sliders to students who don't need them.
This causes accidental parameter changes and confusion.
Lower priority — implement after guided wizard, batch entry, and auto-download are complete.
```

---

```text
Title: PID Learning Overlay
Goal: Visualise P, I, D term contributions separately with hints for understanding PID behaviour
Category: GUI

Importance (1-5): 2
Necessity (1-5): 1
Dependency (0/1): 0
Effort (1-5): 3
Score: 3

Dependencies: Expert / Instructor Mode recommended first
Acceptance Criteria:
- Toggleable overlay showing P, I, D contributions as separate chart series
- Hints shown for extreme values: "High overshoot: lower Kp or increase Kd"
- Only visible in Expert mode

Notes: Educational feature for advanced PID labs.
The primary use case of this project (heatsink comparison) does not involve PID tuning by students.
Very low priority — implement only after all core workflow features are done.
```

---

## Current P0 Priorities (Implement Next)

All five are software-only changes to `server.py` and `index.html`. No firmware required.

| Priority | Item | Score | Why |
|---|---|---|-----|
| 1 | Post-Test Auto Shutdown | 17 | Safety: heater must not stay on after test |
| 2 | Temperature Range / Batch Entry | 16 | Biggest friction point in current Tester |
| 3 | Guided Connection Wizard | 15 | Biggest confusion point for new students |
| 4 | Startup Sensor Health Check | 13 | Prevents silent invalid R_th results |
| 5 | Heatsink ID Input | 12 | Makes result files self-documenting |

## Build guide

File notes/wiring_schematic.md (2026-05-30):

# HeatsinkLab Wind Tunnel — Carrier Board Wiring Schematic

3D-printable carrier board for the ESP32-S3 dev board.  
Traces made with copper tape. All peripherals connect via JST-XH plug-in connectors.

---

## Board Overview

```
┌─────────────────────────────────────────────────────────────────────┐
│                    HeatsinkLab Carrier Board                        │
│                                                                     │
│  [PWR_IN J1]                                                        │
│  12V+ ──┬──► HEATER MOSFET Q1 (IRLZ44N)                           │
│  GND  ──┼──►   DRAIN ──► INA226 V_IN+ ──► INA226 V_IN− ──► [J3]  │
│         │    GATE <── GPIO4 (10kΩ pull-down to GND)                │
│         │    SOURCE ──► GND rail                                    │
│         │                                                           │
│         └──► FAN PWR MOSFET Q2 (IRLZ44N)                          │
│               DRAIN ──► [FAN_OUT J4]                               │
│               GATE <── GPIO10 (10kΩ pull-down to GND)              │
│               SOURCE ──► GND rail                                   │
│                                                                     │
│  ┌─────────────────────────────────────────────────────┐           │
│  │               ESP32-S3 Dev Board                    │           │
│  │         (USB-C powered from lab PC)                 │           │
│  │                                                     │           │
│  │  GPIO4  ────────────────────────► Q1 GATE          │           │
│  │  GPIO5  ──────────────────────────────── [J4 pin3] │           │
│  │  GPIO10 ────────────────────────► Q2 GATE          │           │
│  │  GPIO11 (MISO) ─┐                                  │           │
│  │  GPIO12 (CS)   ─┼──────────────────────────► [J6]  │           │
│  │  GPIO13 (SCK)  ─┘                                  │           │
│  │  GPIO15 (SDA) ──┬───────────────────────────► [J7]  │           │
│  │  GPIO16 (SCL) ──┼───────────────────────────► [J8]  │           │
│  │                 ├───────────────────────────► [J9]  │           │
│  │  3V3 ──────────►┼── sensor VCC rail                │           │
│  │  GND ──────────►┴── common GND rail                │           │
│  └─────────────────────────────────────────────────────┘           │
│                                                                     │
│  On-board passives:                                                 │
│    R1, R2  4.7kΩ  I2C pull-ups (SDA → 3.3V, SCL → 3.3V)          │
│    R3, R4  10kΩ   MOSFET gate pull-downs (Q1, Q2 gate → GND)      │
│    INA226  module soldered in-line in heater power path            │
│                                                                     │
└─────────────────────────────────────────────────────────────────────┘
```

---

## Connector Reference

| Ref | Label | Type | Pins | Pin 1 | Pin 2 | Pin 3 | Pin 4 | Pin 5 |
|-----|---|---|---|---|---|---|---|---|
| J1  | PWR_IN | JST-XH 2p | 2 | 12V+ | GND | — | — | — |
| J2  | HEATER_OUT  | JST-XH 2p | 2 | HEATER+ | HEATER− | — | — | — |
| J3  | INA226_PWR  | *(on-board)* | — | *(series in heater path — not a plug connector)* | | | | |
| J4  | FAN | JST-XH 3p | 3 | FAN+ (12V via Q2) | GND  | GPIO5(PWM)  | — | — |
| J6  | THERMO | JST-XH 5p | 5 | 3.3V | GND | GPIO11(MISO)| GPIO12(CS)  | GPIO13(SCK)|
| J7  | INA226_I2C  | JST-XH 4p | 4 | 3.3V | GND | GPIO15(SDA) | GPIO16(SCL) | — |
| J8  | SDP510 | JST-XH 4p | 4 | 3.3V | GND | GPIO15(SDA) | GPIO16(SCL) | — |
| J9  | EZO_HUM | JST-XH 4p | 4 | 3.3V | GND | GPIO15(SDA) | GPIO16(SCL) | — |
| J10 | EXT1 | JST-XH 4p | 4 | 3.3V | GND | *spare GPIO*| *spare GPIO*| — |

> J7, J8, J9 share the same SDA/SCL traces. Route one I2C bus trace across the board and branch to three side-by-side connectors.

---

## Power Path Detail

### Heater circuit (high current — use wire or wide copper tape ≥10mm)

```
J1 pin 1 (12V+)
    │
    └──► Q1 DRAIN
              │
         INA226 V_IN+
              │
         INA226 V_IN−   ← shunt resistor measures current here
              │
    J2 pin 1 (HEATER+) ──► heater element (+) ──► heater element (−) ──► J2 pin 2 (HEATER−)
                                                                                │
J1 pin 2 (GND) ◄───────────────────────────────────────────────────────────────┘
Q1 SOURCE ──► GND rail
```

### Fan circuit

```
J1 pin 1 (12V+)
    │
    └──► Q2 DRAIN
              │
    J4 pin 1 (FAN+) ──► fan (+)
    J4 pin 2 (FAN−) ──► fan (−) ──► GND rail
Q2 SOURCE ──► GND rail

J4 pin 3 (GPIO5) ──► fan PWM signal wire (if fan has separate PWM input)
J4 pin 2 (GND)
```

> If your fan is a simple 2-wire brushless (12V / GND only with no PWM input), GPIO5 drives Q2 as a second PWM switch and GPIO10 is unused. If the fan has a separate PWM input (3- or 4-wire fan), GPIO5 goes to the PWM pin and Q2 is just the power switch driven by GPIO10.

---

## I2C Bus

```
GPIO15 (SDA) ──┬──[4.7kΩ R1]──► 3.3V
               ├──► J7 pin 3  (INA226)
               ├──► J8 pin 3  (SDP510)
               └──► J9 pin 3  (EZO-HUM)

GPIO16 (SCL) ──┬──[4.7kΩ R2]──► 3.3V
               ├──► J7 pin 4  (INA226)
               ├──► J8 pin 4  (SDP510)
               └──► J9 pin 4  (EZO-HUM)
```

I2C addresses (no conflicts):

| Sensor  | I2C Address |
|---|---|
| SDP510  | 0x40 |
| INA226  | 0x41 |
| EZO-HUM | 0x6F |

---

## GPIO → Connector Map

| ESP32-S3 GPIO | Signal | Goes to |
|---|---|---|
| GPIO 4 | Heater PWM | Q1 gate (on-board)  |
| GPIO 5 | Fan PWM | J4 pin 3 |
| GPIO 10 | Fan power EN | Q2 gate (on-board)  |
| GPIO 11 | SPI MISO | J6 pin 3 |
| GPIO 12 | SPI CS | J6 pin 4 |
| GPIO 13 | SPI SCK | J6 pin 5 |
| GPIO 15 | I2C SDA | J7, J8, J9 pin 3 |
| GPIO 16 | I2C SCL | J7, J8, J9 pin 4 |
| 3V3 | Sensor VCC | J6–J10 pin 1 |
| GND | Common ground  | All connectors pin 2 + 12V GND |
| USB-C | Serial + power | Lab PC |

---

## Copper Tape Trace Guidelines

| Trace type | Minimum width | Notes |
|---|---|---|
| Heater power (12V)  | 15 mm+ | Use stranded wire soldered alongside tape for reliability |
| Fan power (12V) | 10 mm+ | Fan draws less current than heater |
| GPIO signal traces  | 3–5 mm | Very low current |
| I2C SDA/SCL | 3–5 mm | Keep away from heater traces |
| 3.3V sensor rail | 5 mm | Low current (all sensors combined <100 mA) |
| GND plane | Flood fill | Connect all GND pads with wide copper tape pour |

**Solder all trace crossings and connector pads** — copper tape alone has high contact resistance at joints.

---

## Bill of Materials

| Qty | Part | Notes |
|-----|---|---|
| 2 | IRLZ44N N-channel MOSFET | TO-220, logic-level gate (3.3V compatible) |
| 1 | INA226 breakout module | Or bare IC + 0.1Ω shunt resistor |
| 2 | 4.7kΩ resistor | I2C pull-ups, 0805 SMD or through-hole |
| 2 | 10kΩ resistor | MOSFET gate pull-downs |
| 1 | JST-XH 2-pin connector pair  | J1 PWR_IN |
| 1 | JST-XH 2-pin connector pair  | J2 HEATER_OUT |
| 1 | JST-XH 3-pin connector pair  | J4 FAN (12V / GND / PWM) |
| 1 | JST-XH 5-pin connector pair  | J6 THERMO (MAX6675 SPI) |
| 3 | JST-XH 4-pin connector pair  | J7 INA226_I2C, J8 SDP510, J9 EZO_HUM |
| 1 | JST-XH 4-pin connector pair  | J10 EXT1 (future sensor) |
| — | Copper tape (various widths) | 3mm + 10mm + 15mm rolls recommended |
| — | 3D-printed carrier board | Design to fit your ESP32-S3 dev board footprint |

> **JST-XH vs JST-PH:** JST-XH is 2.54mm pitch (standard breadboard pitch) — easier to crimp by hand. JST-PH is 2.0mm pitch — smaller but harder to crimp without the proper tool. Either works; XH is recommended for this build.

---

## Safety Notes

- The heater MOSFET gate pull-down resistor (R3/R4, 10kΩ) is **mandatory** — it ensures the heater stays OFF if the GPIO floats during ESP32 boot.
- The heater power path carries high current. Use **wire soldered to the copper tape** for the 12V+ and HEATER+ runs — copper tape alone will heat up and delaminate under load.
- GND must be continuous across the whole board. Bridge ESP32 GND, 12V GND, and all sensor GNDs at a single point to avoid ground loops.
- `SET RUN OFF` is sent by the firmware/backend when the test completes. The MOSFET gate pull-down provides a hardware backup if the ESP32 resets unexpectedly.

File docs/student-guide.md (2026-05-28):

# HeatsinkLab Wind Tunnel — Student Guide

**Thermal Characterisation of Heatsinks**

---

> **Safety — read before touching anything**
>
> - The ceramic heater element and copper spreader plate reach high temperatures during a test. **Never touch the copper plate during or after a test** — it stays hot for several minutes after shutdown.
> - **Never turn on the lab power supply until the very last step.** All cables must be connected first.
> - If the temperature on the screen climbs unexpectedly or the system behaves oddly, click **Stop** immediately and call the lab supervisor.

---

## Part 1 — Hardware Setup

Follow these steps every time you set up the wind tunnel for a new test session.

---

### Step 1 — Mount the heatsink onto the heater module

Clip the heatsink under test firmly onto the copper spreader plate on the heater module. Press it flat — a loose heatsink gives inaccurate results.

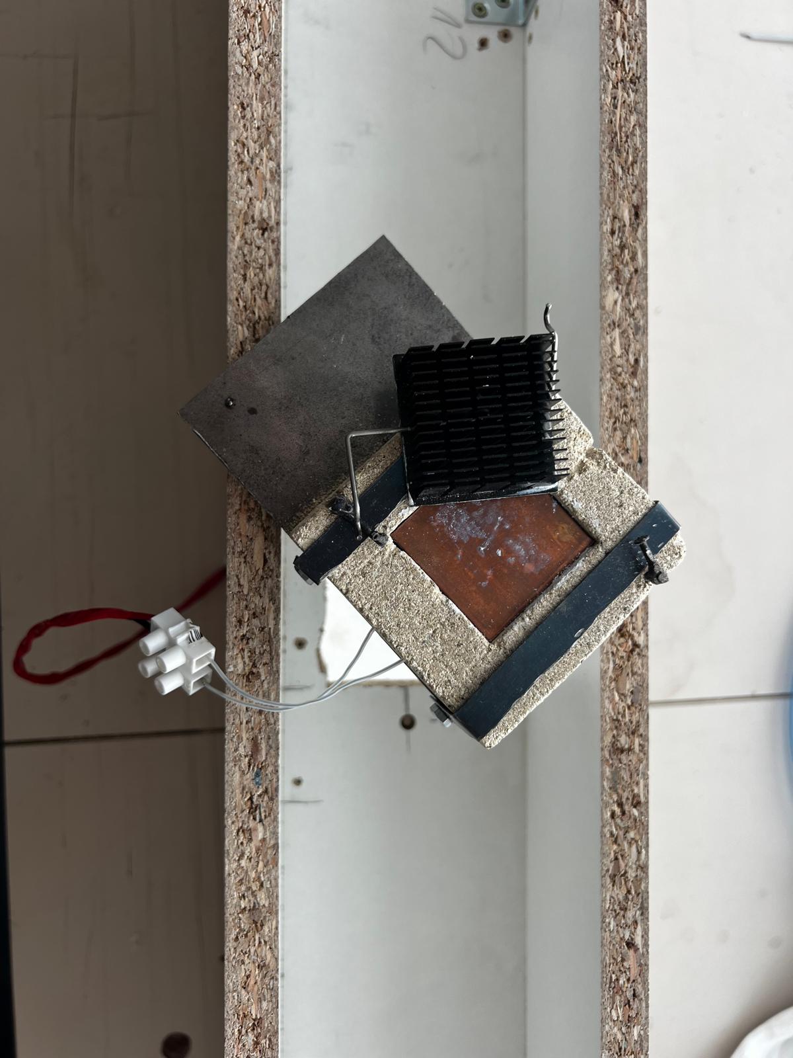
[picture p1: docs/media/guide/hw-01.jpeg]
Install heatsink onto heater module

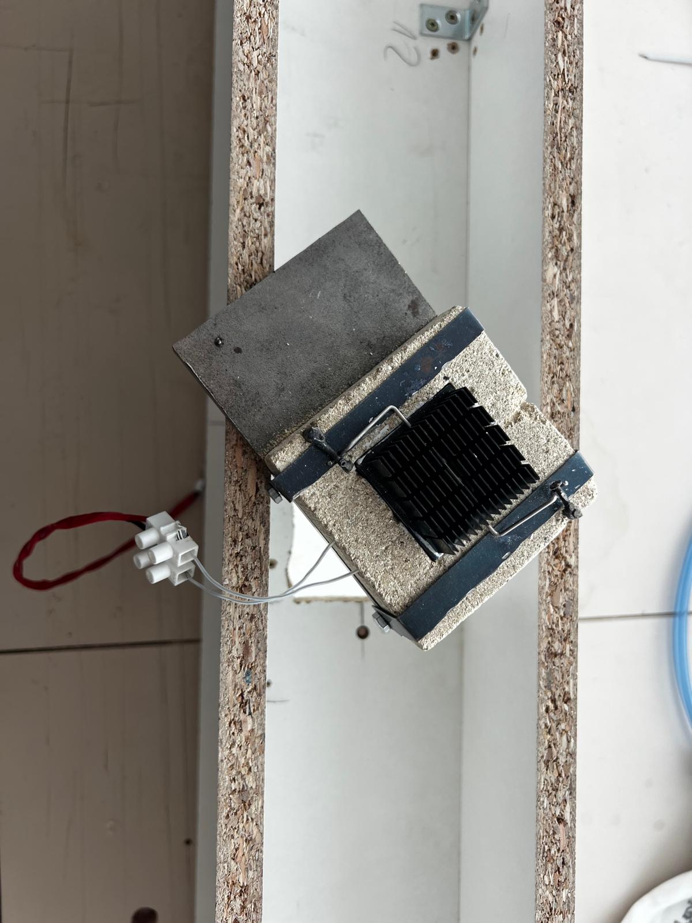
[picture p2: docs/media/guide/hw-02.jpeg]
Heatsink correctly installed on heater module


---

### Step 2 — Insert the heater module into the wind tunnel

Slide the heater module into the opening in the wind tunnel. Route the heater wire harness out through the side cutout in the plexiglass channel.

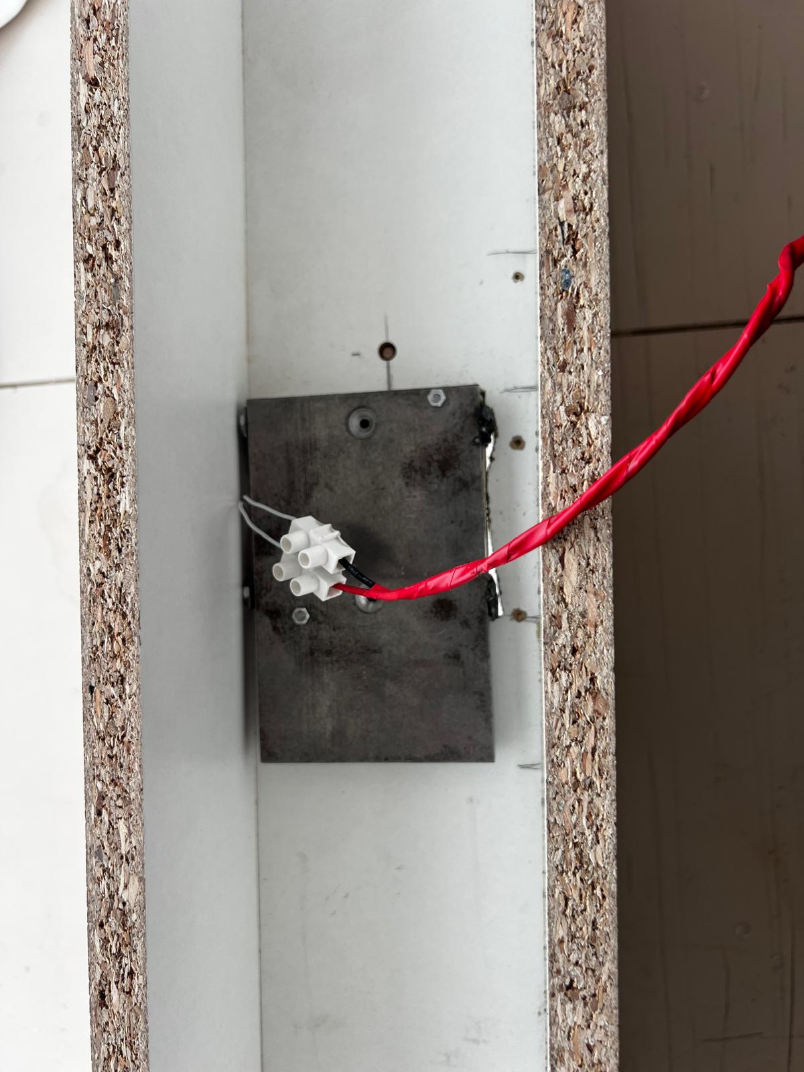
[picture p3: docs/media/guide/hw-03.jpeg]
Heater module placed into wind tunnel


---

### Step 3 — Insert and connect the thermocouple

Push the thermocouple probe firmly all the way into the drilled hole in the copper plate. It must be fully seated to read temperature accurately.

Then connect the other end of the thermocouple cable to the **MAX6675 thermocouple module** on the PCB. The module has a small two-pin terminal block — insert the two thermocouple wires (one per terminal) and tighten the screws. Polarity matters: the **negative wire** (usually red on a K-type thermocouple) goes to the **−** terminal, and the **positive wire** goes to the **+** terminal. If the temperature reads 0 °C or jumps erratically after connecting, swap the two wires.

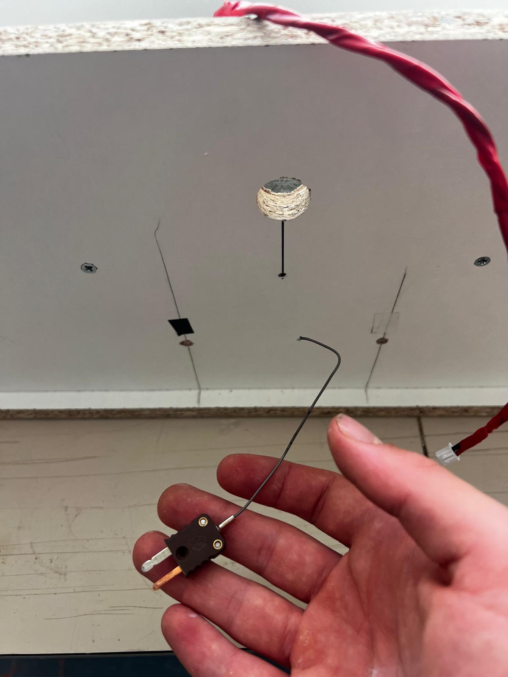
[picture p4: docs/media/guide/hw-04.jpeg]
Installing thermocouple into copper plate

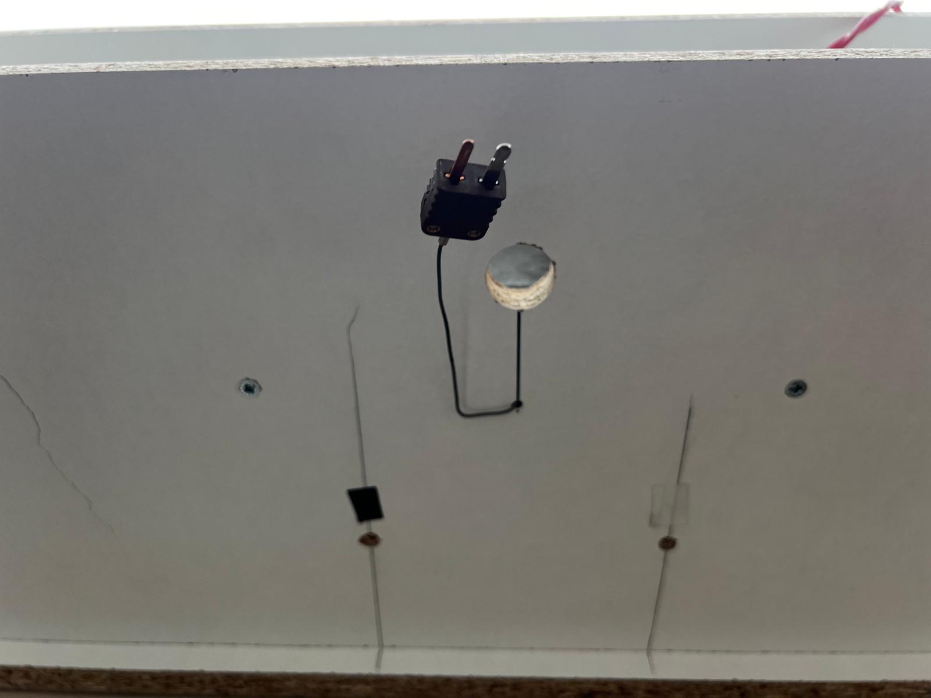
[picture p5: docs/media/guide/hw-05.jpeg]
Thermocouple correctly installed


---

### Step 4 — Mount the PCB

Place the control PCB onto the heater plate module.

> **Important:** Place the isolating pad between the metal frame and the PCB before setting it down. Skipping this can cause a short circuit.

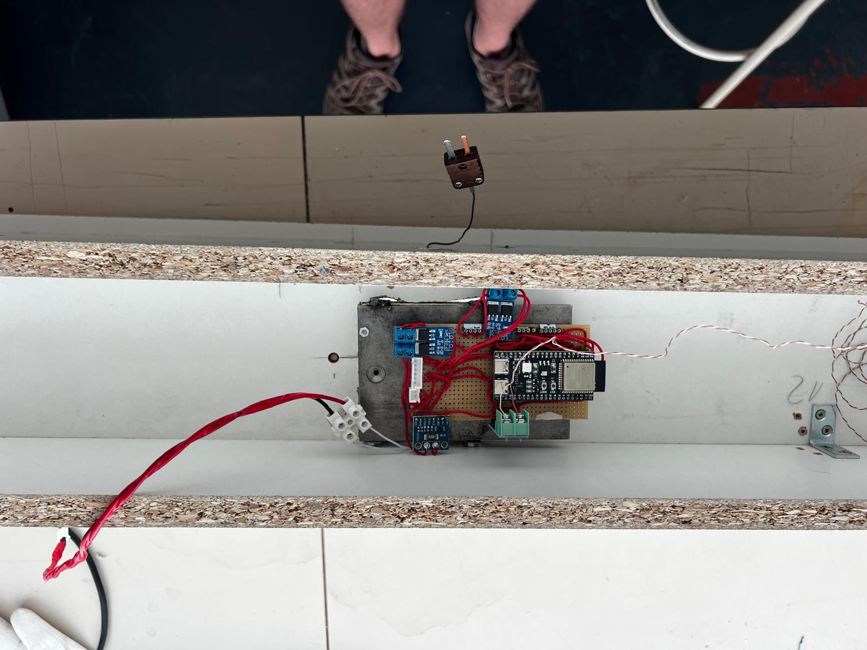
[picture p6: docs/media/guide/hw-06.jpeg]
PCB mounted onto heater plate module


---

### Step 5 — Connect the pressure sensor cable to the sensor

The cable connector is keyed with a white tape marker. Match the white tape on the cable to the white tape mark on the pressure sensor — **direction matters**.

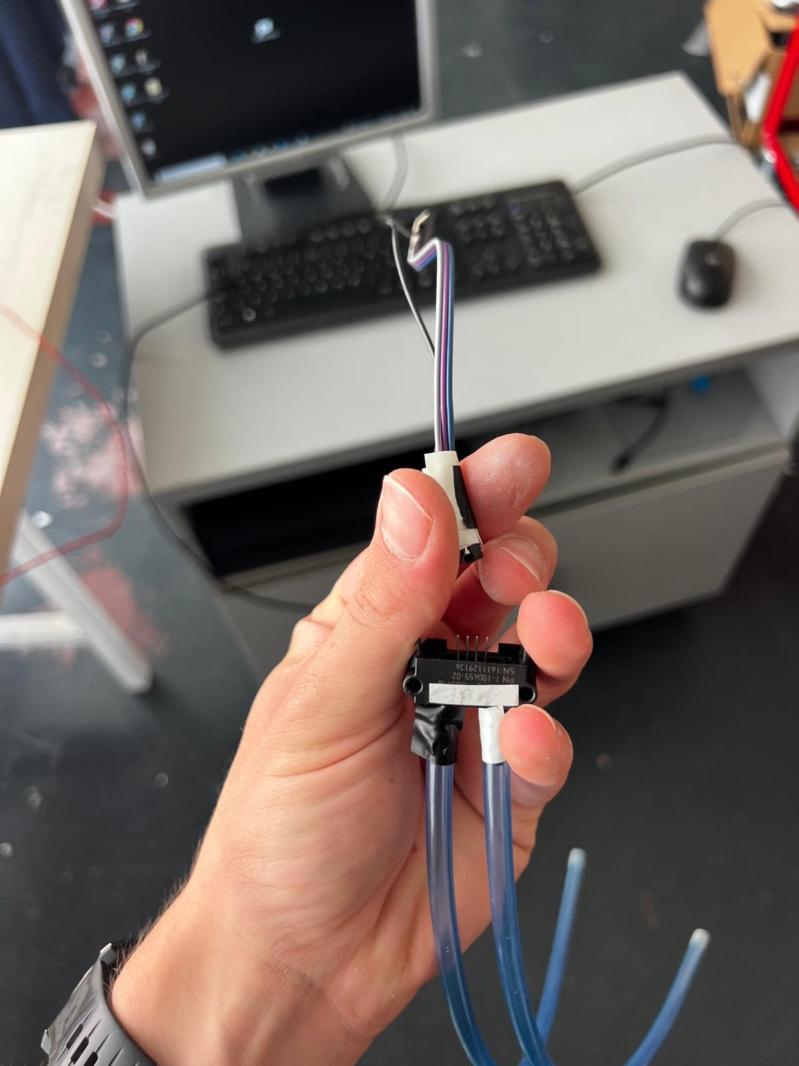
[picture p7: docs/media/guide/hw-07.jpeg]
Connecting cable to pressure sensor (white tape alignment)

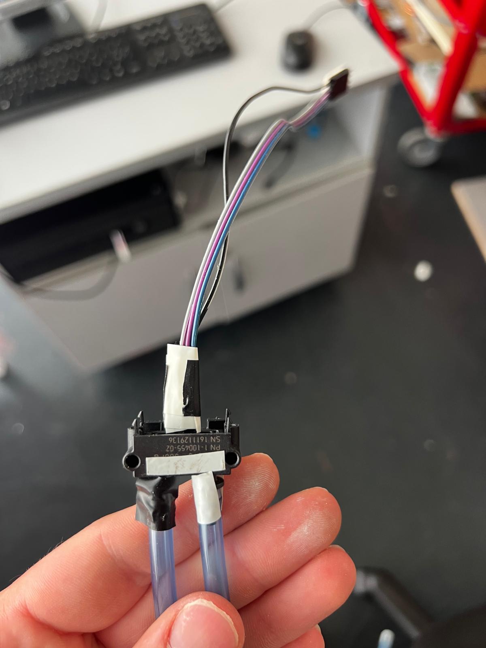
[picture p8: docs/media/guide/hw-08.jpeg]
Pressure sensor cable correctly connected


---

### Step 6 — Connect the pressure sensor tubes to the wind tunnel

The silicone tubes are colour-coded. Match each tube colour to the corresponding port on the wind tunnel.

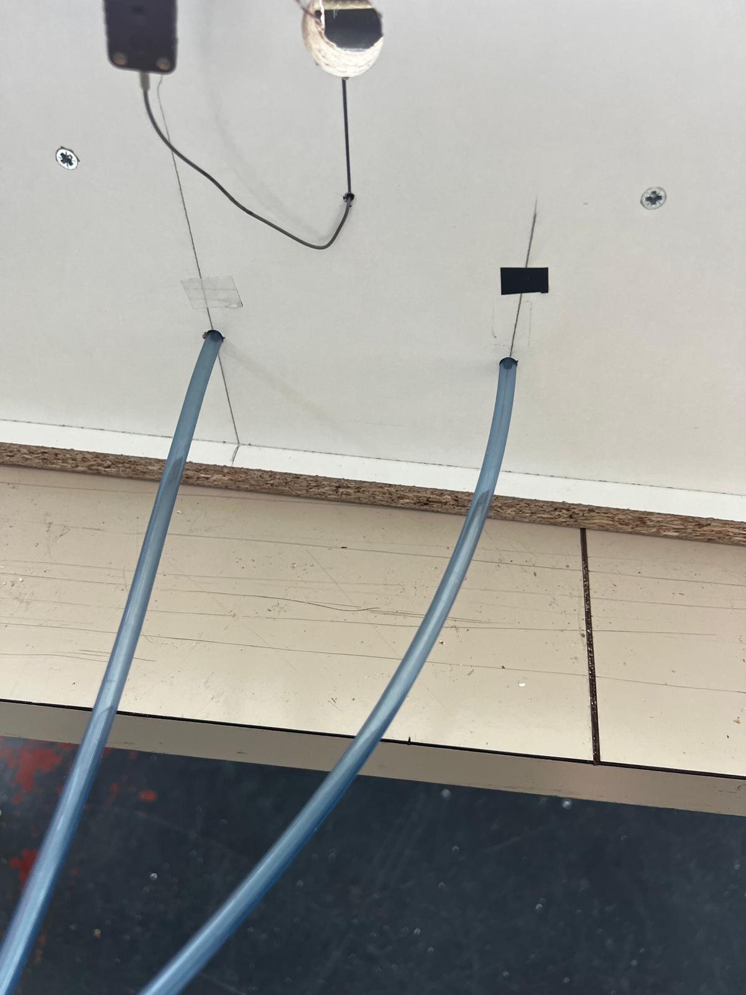
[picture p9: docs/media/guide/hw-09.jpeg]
Pressure sensor tubes connected to wind tunnel

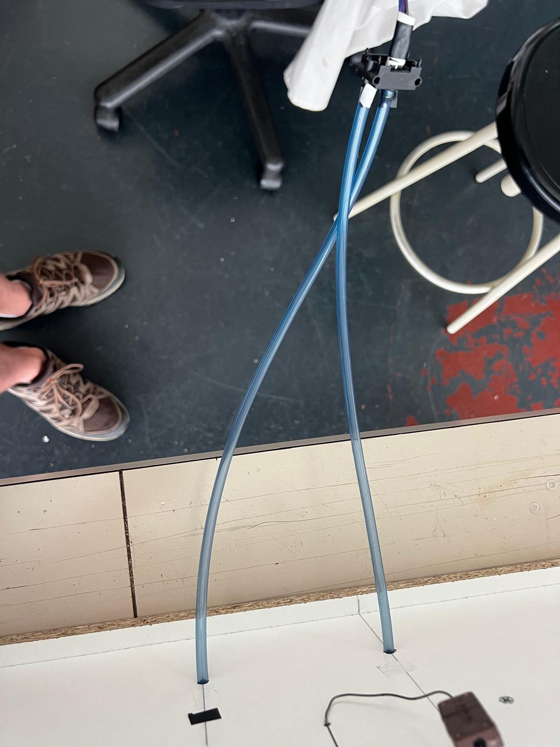
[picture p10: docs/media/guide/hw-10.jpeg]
Other view — colour-coded tubes


---

### Step 7 — Connect the pressure sensor cable to the PCB

Plug the P1 connector into the P1 socket on the PCB. The white tape marker must face the same direction on both ends.

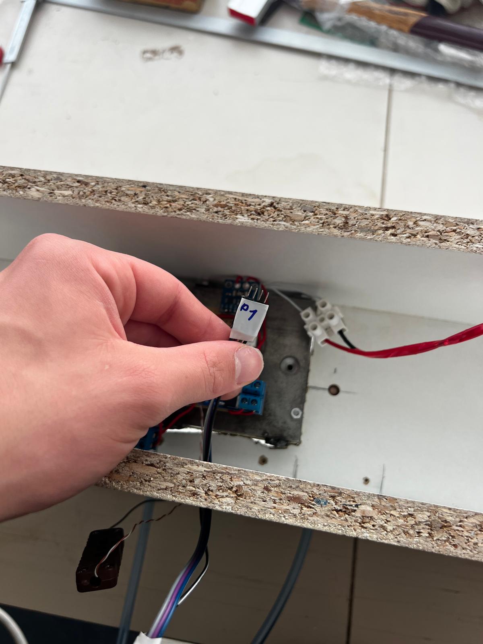
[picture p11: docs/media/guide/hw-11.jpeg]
P1 cable ready to connect to PCB (white tape alignment)

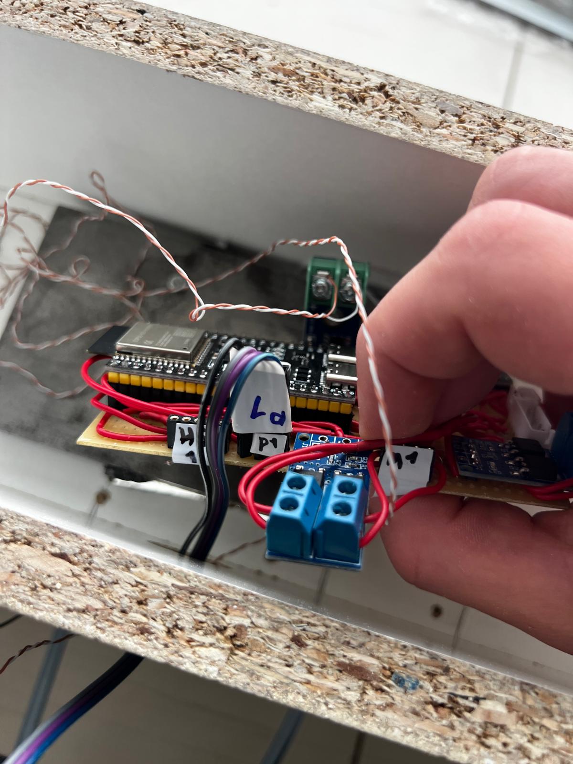
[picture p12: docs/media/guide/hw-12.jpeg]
P1 cable correctly connected to PCB


---

### Step 8 — Connect the heater plate cable to the PCB

The heater plate wire harness has a matching socket on the PCB. Press it in until it clicks.

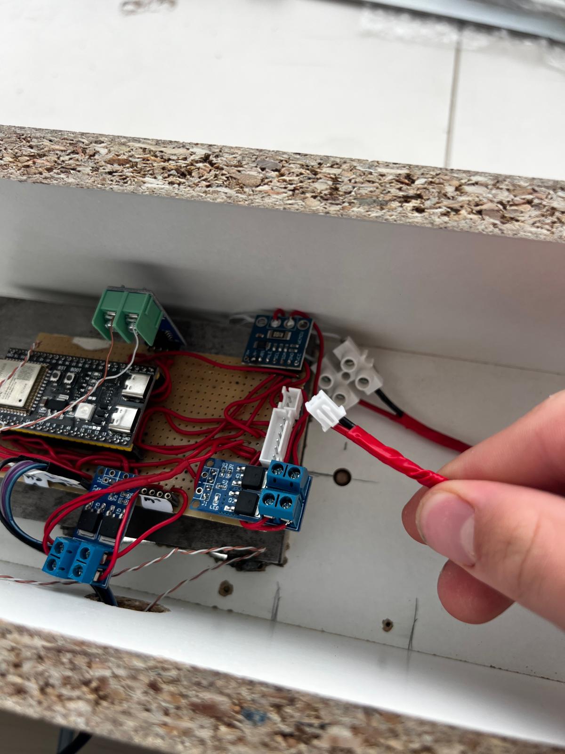
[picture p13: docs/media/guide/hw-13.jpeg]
Heater plate cable ready to connect

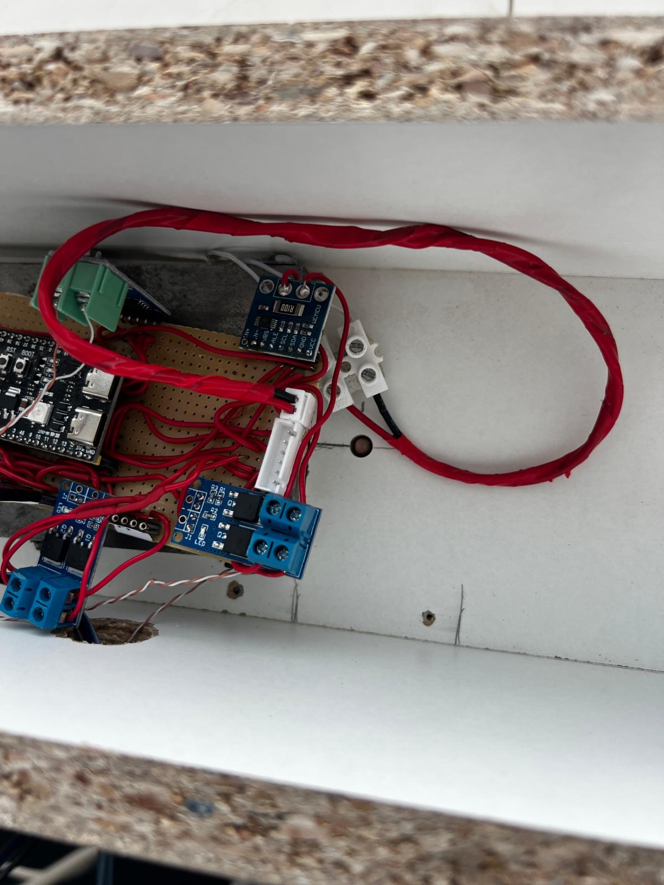
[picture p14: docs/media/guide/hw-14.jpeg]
Heater plate cable correctly connected to PCB


---

### Step 9 — Connect the motor (fan) cable to the PCB

The fan motor cable also uses the white tape alignment rule. M1 on the cable connects to M1 on the PCB.

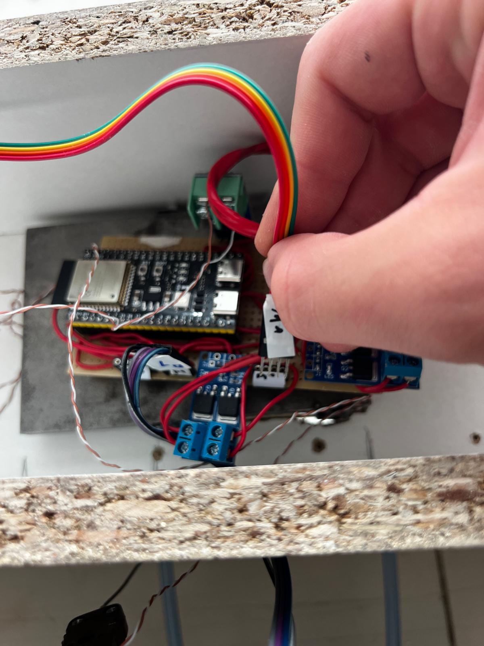
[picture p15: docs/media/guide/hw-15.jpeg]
Motor cable ready — white tape alignment, M1 to M1

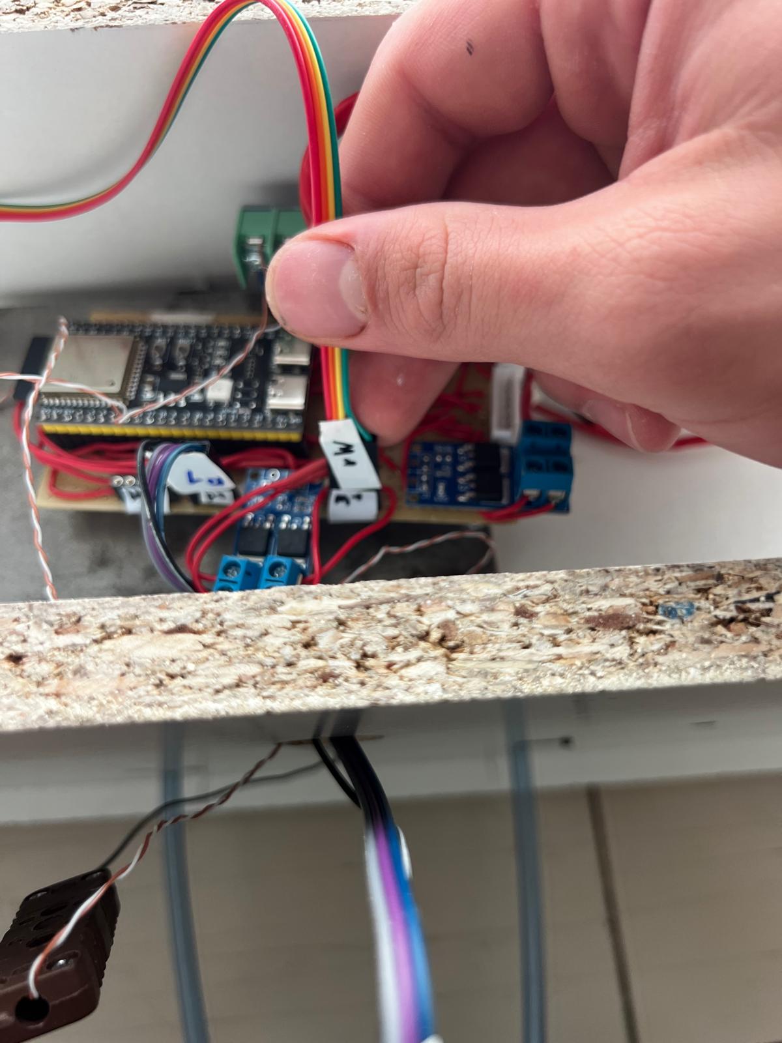
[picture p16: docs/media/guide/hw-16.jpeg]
Motor cable correctly connected


---

### Step 10 — Connect the humidity sensor cable to the PCB

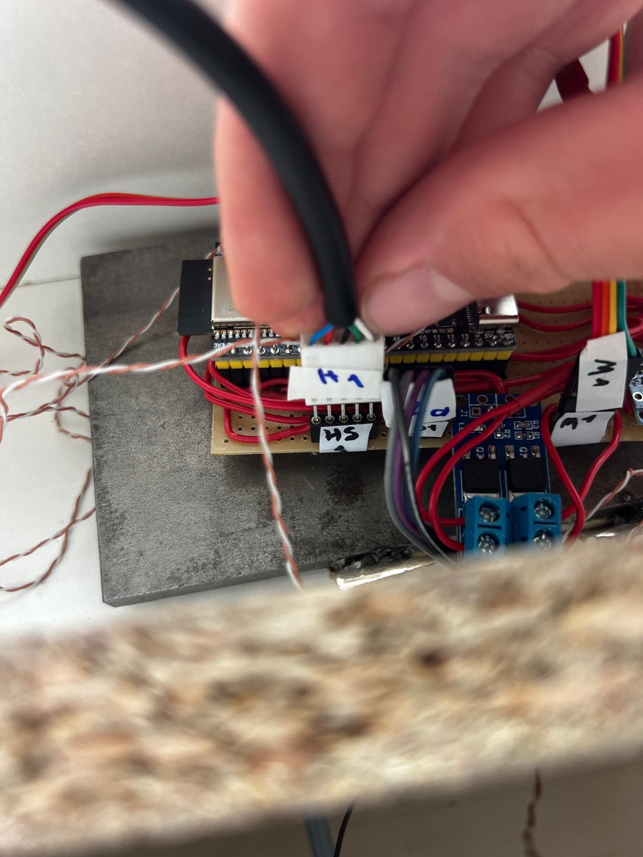
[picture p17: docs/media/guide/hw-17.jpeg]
Humidity sensor cable correctly connected to PCB


---

### Step 11 — Verify all connectors

Step back and look at the PCB. Every connector should be fully seated. Compare with the photo below.

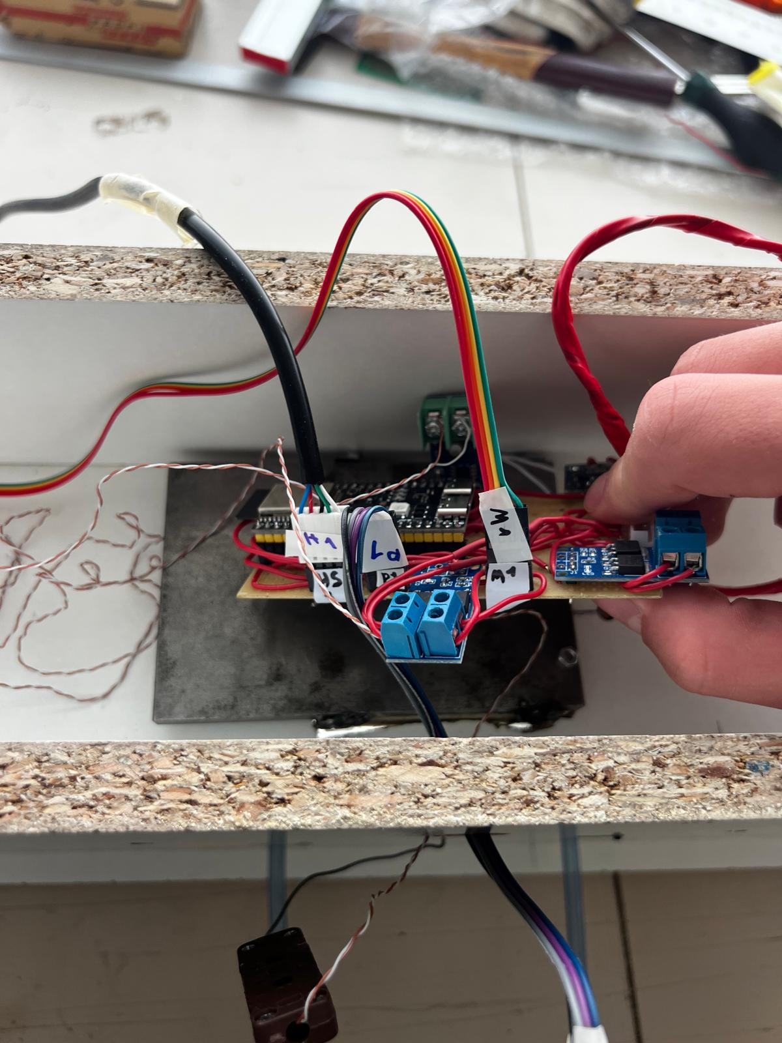
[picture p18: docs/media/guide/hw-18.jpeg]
All sensor cables correctly connected


---

### Step 12 — Verify lab power supply voltage

Turn on the lab power supply briefly and confirm the display reads **12 V**. Then **turn it off again** — do not leave it on while connecting the remaining cables.

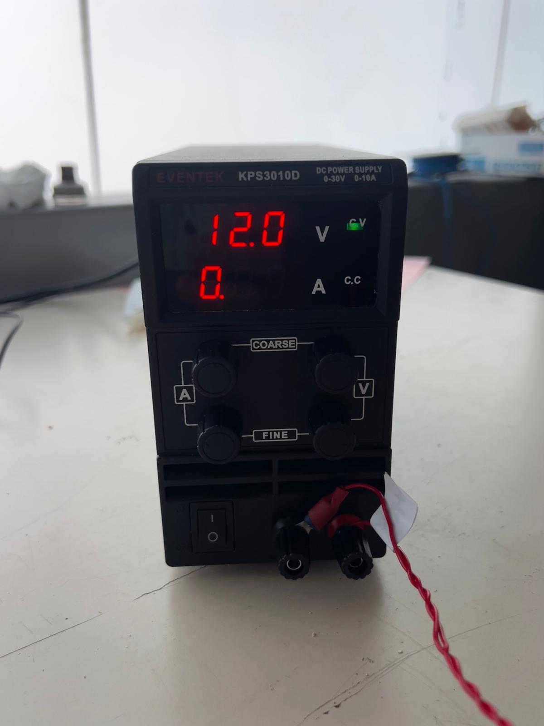
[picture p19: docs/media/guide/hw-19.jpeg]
Power supply showing 12 V — turn off before proceeding


---

### Step 13 — Connect the power cable to the PCB

With the power supply off, plug the power cable into the PCB power connector.

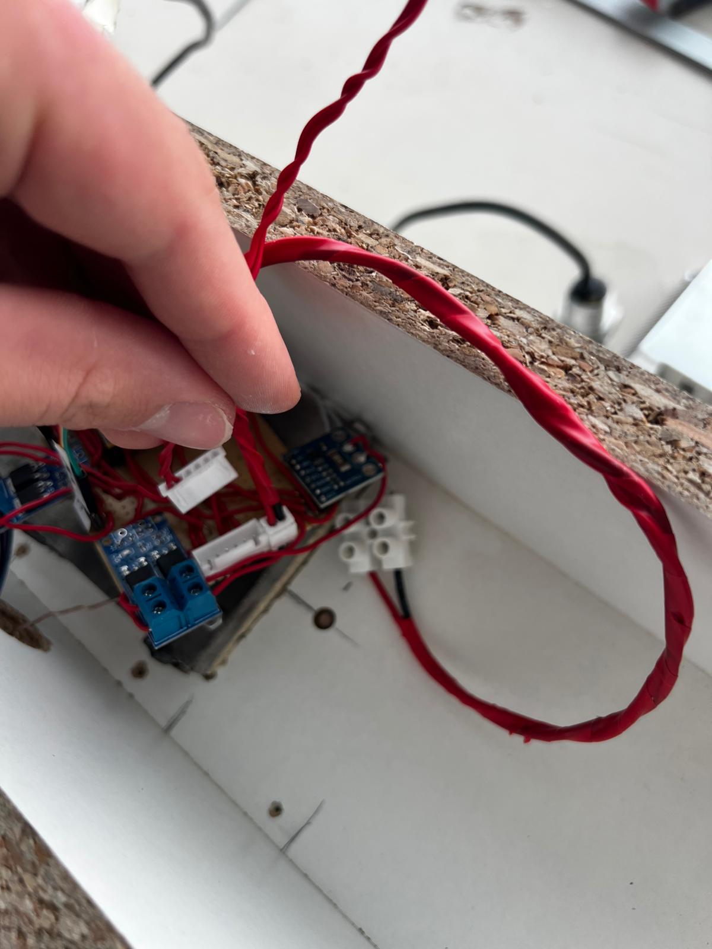
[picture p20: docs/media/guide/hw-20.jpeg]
Installing power cable to PCB

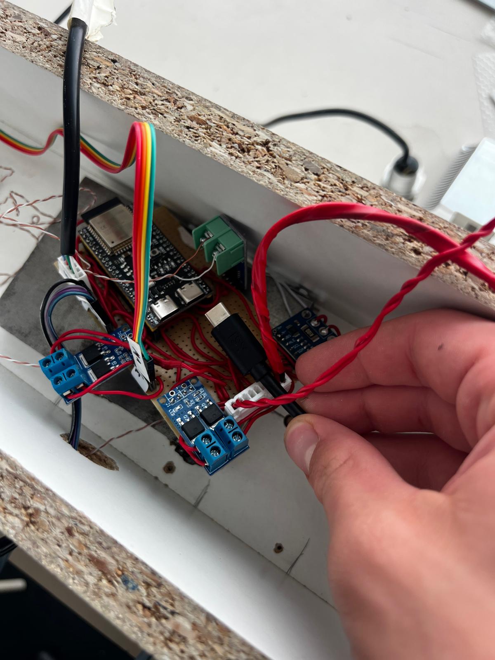
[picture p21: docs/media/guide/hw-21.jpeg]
Power cable correctly connected


---

### Step 14 — Connect the USB-C cable to the ESP32

The USB-C port is on the ESP32 board mounted on the PCB. Connect the cable from the bench to the ESP32.

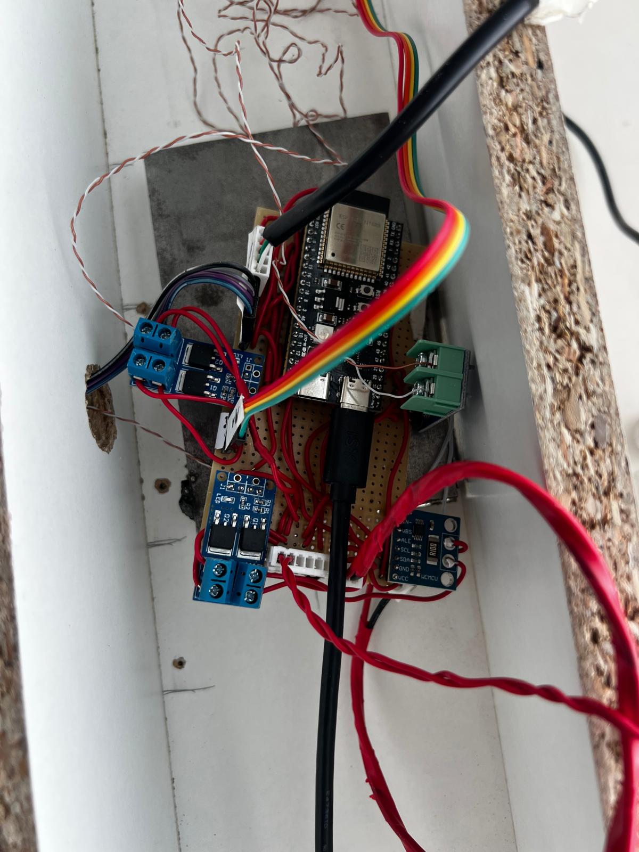
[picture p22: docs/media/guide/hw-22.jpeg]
USB-C cable connected to ESP32


---

### Step 15 — Connect USB-C to the PC, then turn on the power supply

Plug the other end of the USB-C cable into the lab PC.

**Only now** switch on the lab power supply. Powering the rig is always the final step.

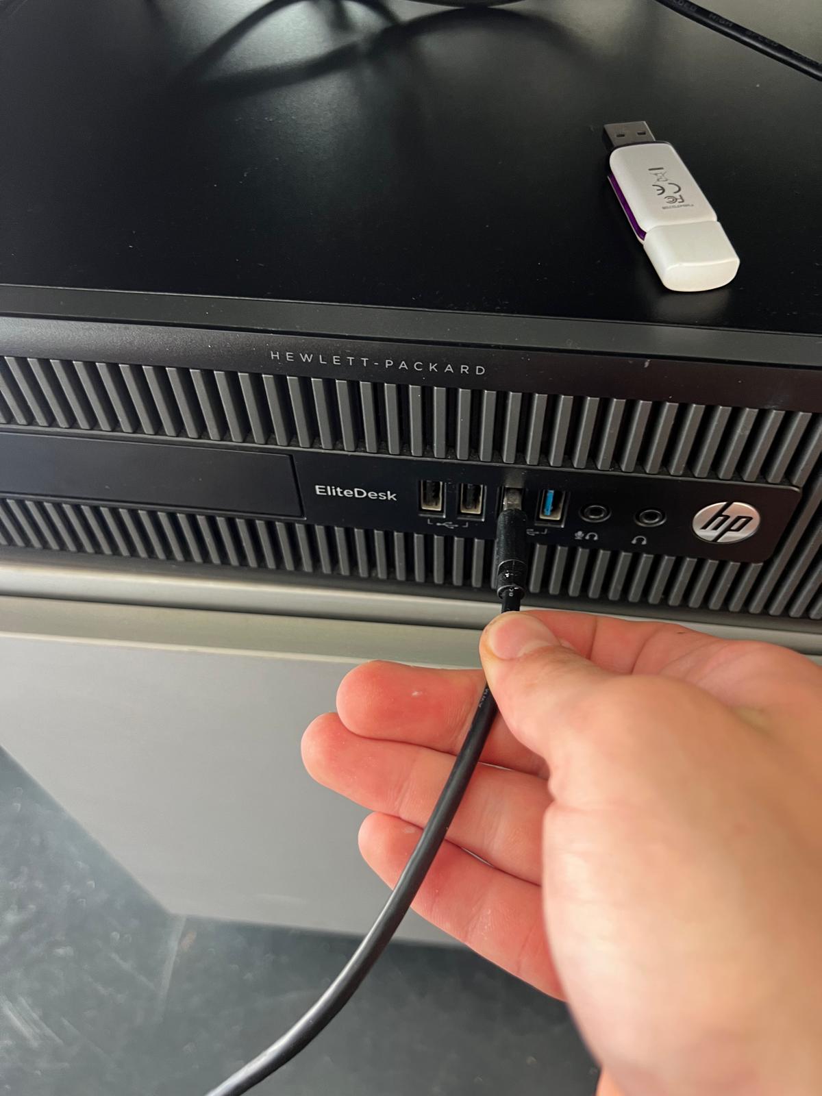
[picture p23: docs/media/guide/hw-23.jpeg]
USB-C into PC — then turn on lab power (LAST step)


---

## Part 2 — Software Guide

---

### Step 1 — Launch the software

Double-click the **HEATSINK TESTER** shortcut on the lab PC desktop. A browser tab opens automatically at `localhost:8765`.

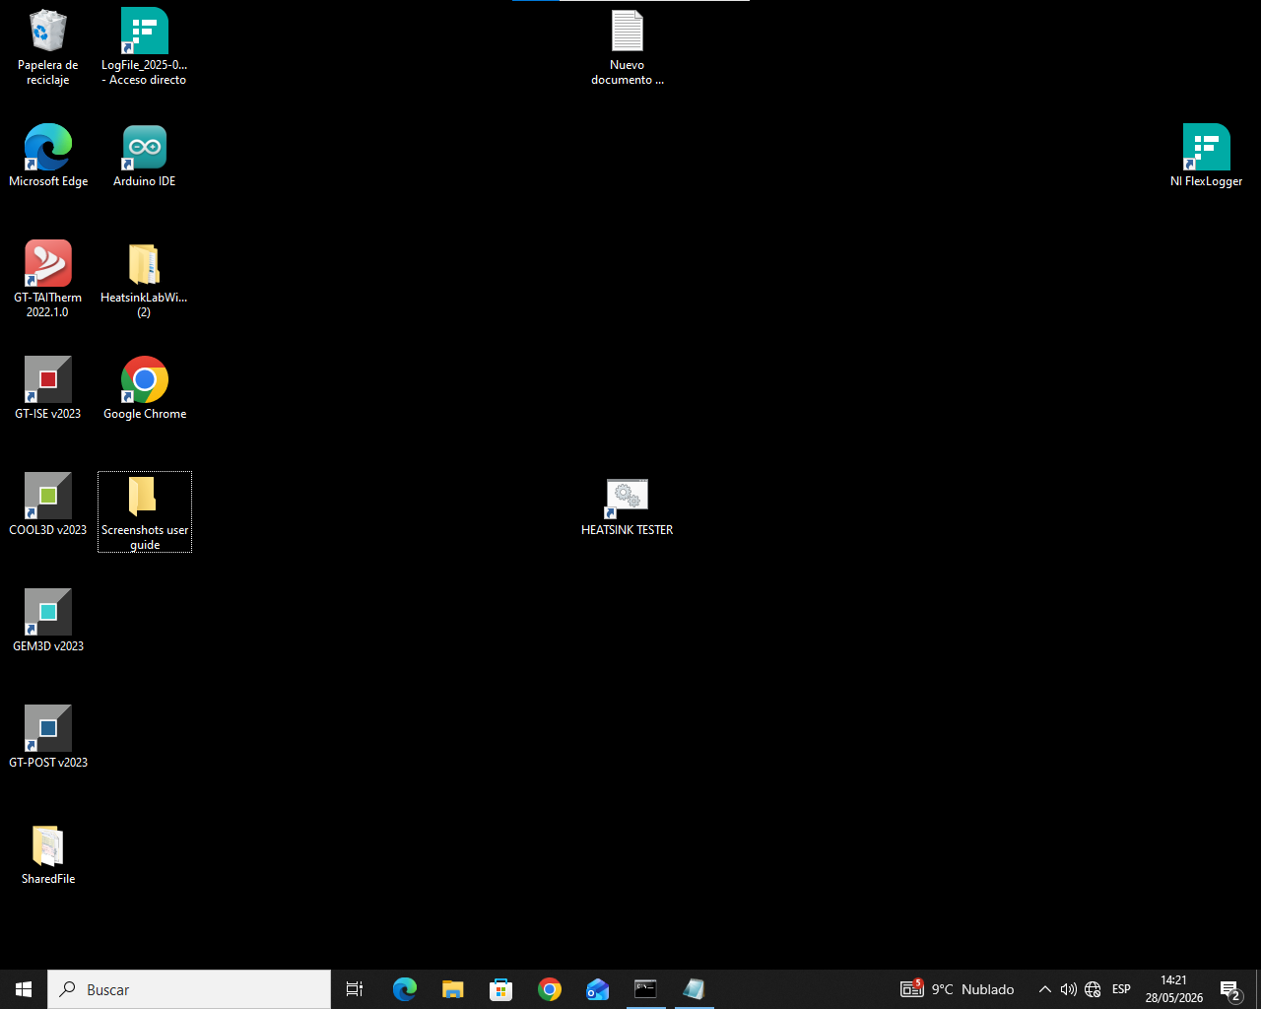
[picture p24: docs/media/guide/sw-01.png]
Lab PC desktop with HEATSINK TESTER shortcut

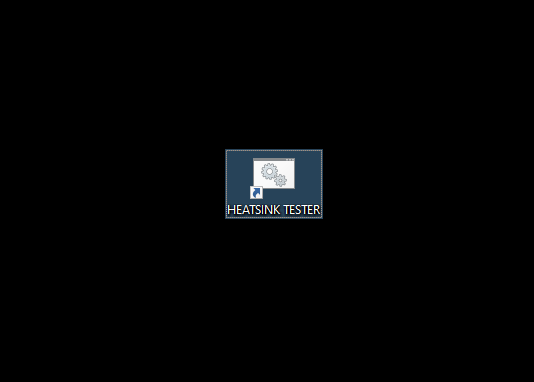
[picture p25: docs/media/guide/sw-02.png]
HEATSINK TESTER shortcut close-up

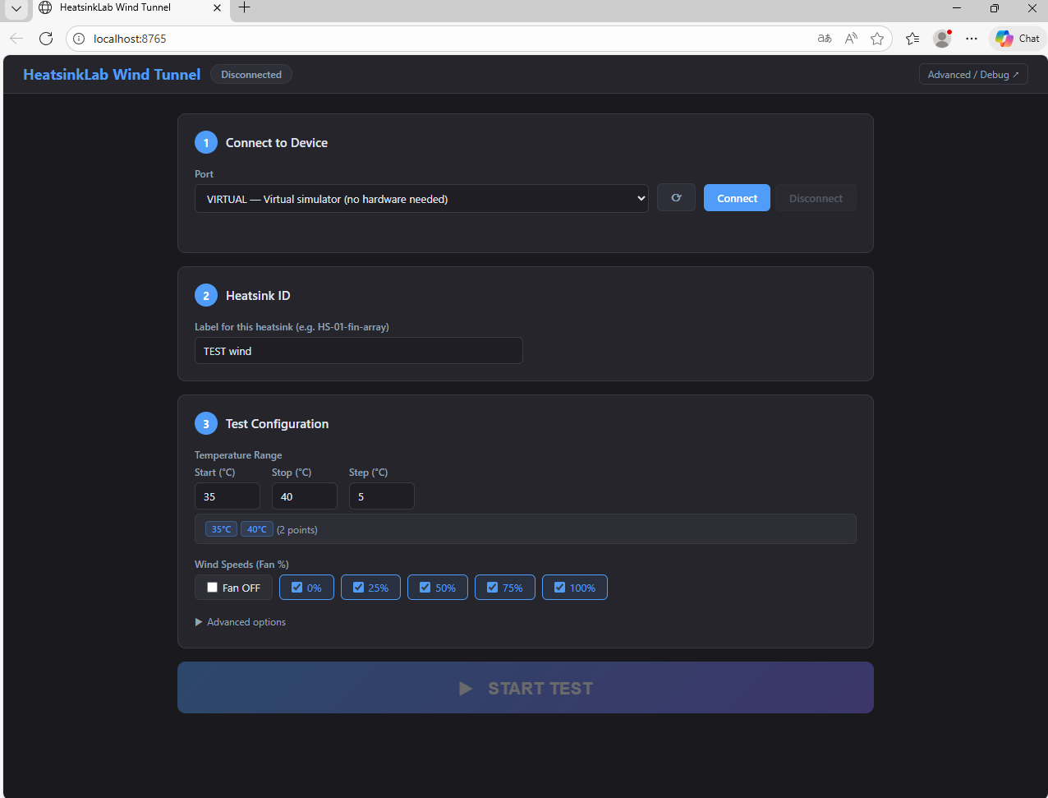
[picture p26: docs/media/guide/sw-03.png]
HeatsinkLab Wind Tunnel GUI opens in browser


---

### Step 2 — Refresh the port list

After plugging in the USB cable, click the **⟳ refresh button** next to the port dropdown. The ESP32 will appear as a new COM port in the list.

Press the refresh button after plugging in the ESP32

---

### Step 3 — Select the COM port

Open the port dropdown and select the entry labelled **"COM3 — USB Serial Device"** (the number may be different on your PC).

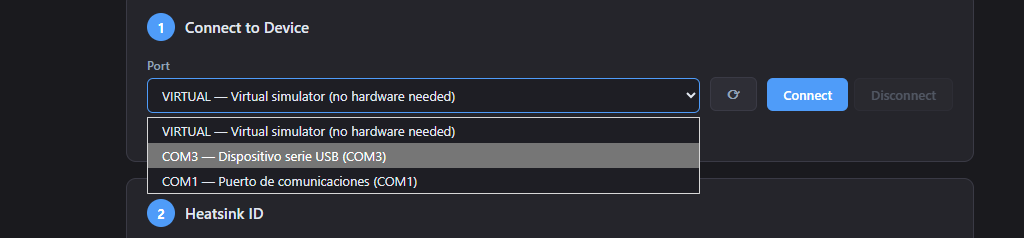
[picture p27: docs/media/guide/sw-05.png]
Port dropdown open — select the USB Serial Device entry


---

### Step 4 — Click Connect

With the COM port selected, click **Connect**. Wait a few seconds until the status shows:

> ✅ **Connected - Device OK** &nbsp;·&nbsp; *Device verified — ready to test.*

COM port selected, ready to click Connect
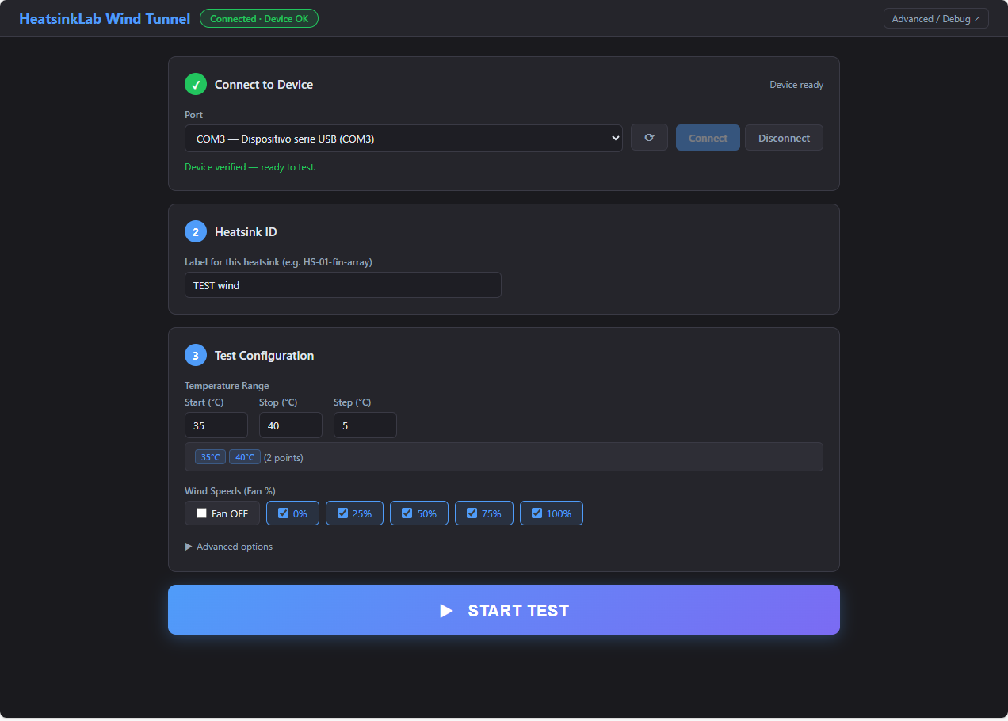
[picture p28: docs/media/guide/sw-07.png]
Device connected and verified — test configuration visible


---

### Step 5 — Enter the Heatsink ID

In the **Heatsink ID** field, type the code written on your heatsink sample (for example `HS-01-fin-array`). This label is saved in the results file so you can identify the data later.

*(Refer to screenshot above — Heatsink ID field is directly below the connection panel.)*

---

### Step 6 — Set the temperature range

In the **Test Configuration** panel, enter:

| Field | Meaning | Example |
|---|---|---|
| **Start (°C)** | Lowest test temperature | `40` |
| **Stop (°C)** | Highest test temperature | `80` |
| **Step (°C)** | Gap between steps | `10` |

The preview chips (e.g. `40°C  50°C  60°C  70°C  80°C`) show exactly which temperatures will be tested.

*(Refer to screenshot above.)*

---

### Step 7 — Select wind speeds

Tick the fan speed percentages you want to include in the test. Common choices:

- **Fan OFF** — natural convection, no airflow
- **0%, 25%, 50%, 75%, 100%** — forced convection at different speeds

You can tick multiple speeds; the system will run a full temperature sweep at each selected speed automatically.

*(Refer to screenshot above.)*

---

### Step 8 — Start the test

Click the large **▶ START TEST** button. The system takes over completely from this point.

A **Test in Progress** panel appears showing:
- Current fan speed and step number
- Current status (e.g. *"Heating to 40°C…"*)
- Live readouts: **Temperature**, **Setpoint**, **Power (W)**, **Eq. PWM**, and **R_th (°C/W)**
- A real-time temperature chart

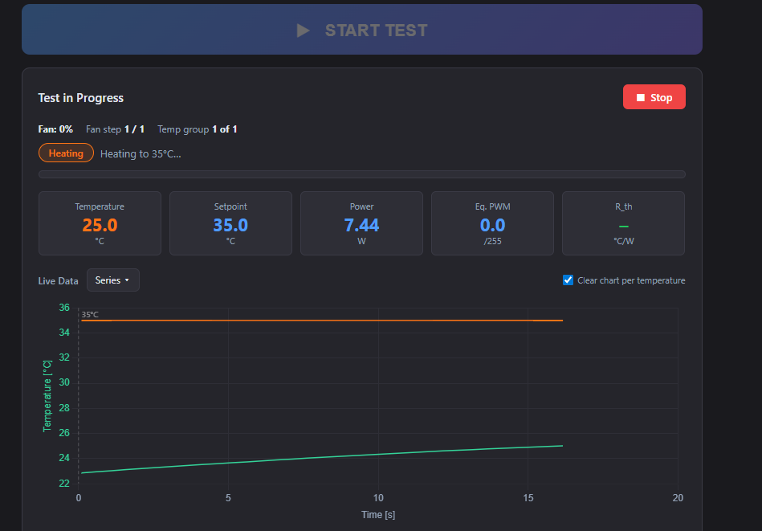
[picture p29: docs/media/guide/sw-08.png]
Test in progress — live data panel and chart


---

### Step 9 — Wait — do not touch anything

The system works through each temperature step on its own:

1. Heats to the target temperature
2. Waits until the temperature is stable (±0.5 °C)
3. Holds for the soak period
4. Records the result
5. Moves to the next step

Typical test duration: **10–30 minutes** depending on how many steps and fan speeds are selected.

---

### Step 10 — Download the results

When all steps are complete, a **Results** table appears at the bottom of the page showing one row per temperature step.

Click **↓ Results CSV** to save the summary to your PC.

> Also save **↓ Raw CSV** if you need the full telemetry log for detailed analysis.

Results table with download buttons

---

### Step 11 — Remove the heatsink and repeat

1. Wait for the temperature readout to drop below **35 °C** before handling any components.
2. Unclip the tested heatsink from the copper plate.
3. Mount the next heatsink (back to Part 1, Step 1).
4. Return to **Part 2, Step 5** — enter the new Heatsink ID and start the next test.

> **Do not disconnect the USB or restart the software** between back-to-back tests on the same session.

---

## Troubleshooting

| Symptom | What to try |
|---|---|
| COM port doesn't appear in the dropdown after plugging in USB | Press the **⟳ refresh** button; try a different USB port on the PC |
| "Connecting…" hangs indefinitely | Unplug and replug the USB cable; close and reopen the browser tab |
| Temperature reads 0 °C | Check the thermocouple plug is fully seated in the PCB connector |
| Power reads 0 W | Check the heater plate cable connector on the PCB |
| Pressure reads nothing | Check the P1 cable at both ends; white tape must align on both connectors |
| R_th shows NaN | Power reading is 0 (divide by zero) — see "Power reads 0 W" above |
| HEATSINK TESTER shortcut does nothing | Call the lab supervisor — the server may need to be restarted |

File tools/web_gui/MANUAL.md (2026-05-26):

# HeatsinkLab Wind Tunnel — User Manual

## Requirements

- Windows 10 or 11 (Linux / macOS work too)
- Python 3.10 or newer ([python.org](https://python.org) or `winget install Python.Python.3.12`)
- No other software needed

## Installation

1. Download and unzip the project from GitHub
2. Open a Command Prompt in the `tools/web_gui` folder
3. Run: `pip install -r requirements.txt`
4. Or simply double-click `start.bat`

## Starting the server

Double-click `start.bat` — a browser window will open at **http://localhost:8765**

> If the tab does not open automatically: navigate to http://localhost:8765 manually.

## Connecting to the device

1. Plug the ESP32-S3 into the PC via USB
2. Select the correct COM port from the dropdown (e.g. `COM4 — USB Serial Device`)
3. Click **Connect** — the telemetry chart starts updating within a few seconds

> **No hardware?** Select **VIRTUAL** from the port dropdown to use the built-in simulator. All GUI features work in virtual mode.

---

## Normal Mode — Controls

### Setpoint

Enter a target temperature in °C. The firmware PID loop will drive the heater toward this value.

### Control Modes

| Mode | Behaviour |
|---|---|
| AUTO | PID loop continuously adjusts heater PWM toward setpoint |
| MANUAL | Fixed PWM set by the `MANPWM` slider |
| SMART | PID until stable (±0.5 °C for 8 s), then locks equilibrium PWM. Used automatically in Tester mode. |

### Fan Speed

The fan speed slider (0–100 %) controls cooling airflow through the tunnel. 0 = natural convection only.

### Fan Power (FANPWR)

A separate toggle cuts power to the fan motor entirely via MOSFET (GPIO 10), guaranteeing zero airflow for natural-convection tests. This is distinct from setting fan speed to 0 %.

---

## Run Metadata

Before starting CSV recording, optionally fill in:

- **Run ID** — a short label (e.g. `run_001`) written into the CSV header
- **Heatsink** — identifies the heatsink under test (e.g. `HS_finned_A`)

These values appear as comment lines at the top of the CSV:

```
# schema_version: 4
# run_id: run_001
# heatsink_id: HS_finned_A
# start_time: 2026-03-29T14:30:22
```

---

## CSV Column Customisation

Clicking **Start CSV** opens a dialog where you can select exactly which columns to record. Columns are grouped by category (Basic, Temperature, PID Details, Smart Mode, Fan, Power, Sensors). An Excel Power Query import formula is generated automatically based on your selection.

---

## Phase Markers

While recording, click **📌 Marker** to stamp the current moment with a label. The marker:
- Adds an orange dashed vertical line to the chart
- Writes a row to the CSV with the label in the `event` column

---

## Presets

The **Presets** section in the sidebar lets you save and restore named configurations:

- Three built-in presets are provided (Default, Aggressive, Conservative)
- **Save Current** — saves all parameter values under a name you choose
- **Load** — applies the selected preset immediately
- **Delete** — removes a saved preset

Presets are stored in `tools/web_gui/presets.json`.

---

## Expert / Student Mode

Click **🎓 Student** in the top bar to hide advanced parameters (ALPHA, MAXSTEP, ENTERCNT, EXITCNT, BIAS, SPBIAS, PID debug series, and advanced telemetry fields). The toggle state is remembered across sessions.

---

## Ambient Temperature

Enter the current room temperature (°C) in the **Ambient (°C)** field in the sidebar. This value is used by the Tester mode to calculate thermal resistance (R_th). The Tester panel includes its own Ambient input that stays synchronised.

---

## Performance Metrics

The **Performance Metrics** panel computes step-response statistics from the current chart history:

| Metric | Meaning |
|---|---|
| Rise Time | Time to reach 90 % of the setpoint step |
| Settle Time | Time until temperature stays within ±2 °C of setpoint for 10 s |
| Overshoot % | Peak exceedance relative to step size |
| SS Error °C | Mean steady-state error over the last 20 samples |
| IAE (°C·s) | Integral of absolute error — lower is better |

Click **Compute** or enable **Auto on SP change** to trigger automatically when the setpoint changes by more than 2 °C.

---

## Graph Cursor / Probe Tool

Click **Cursor: OFF** in the chart controls to enable a crosshair overlay. While active:
- Hovering over the chart shows all visible series values at that time
- Clicking the chart **pins** the tooltip; click again to unpin

---

## Differential Pressure Sensor

If the Sensirion SDP510 is connected, the sidebar shows live readings:

| Reading | Meaning |
|---|---|
| DELTA_P1 | Raw differential pressure (Pa) |
| DELTA_P1F | EMA-filtered pressure (Pa) |

**Taring (zeroing):** Click **Tare Zero** in the Pressure section to record the current offset as the zero reference. All subsequent readings are shown relative to this baseline. Click **Reset Zero** to remove the offset and show raw sensor values.

The zeroing offset is applied in the backend and broadcast to all connected clients. Tare before each test run with no airflow to remove any sensor drift.

---

## Tester Mode

For running systematic heatsink characterisation tests:

1. Click **Tester** in the top bar
2. Enter the ambient (room) temperature in °C
3. Choose the **Fan condition**:
   - **Fan ON** — select a fan speed % and click **Set**
   - **Fan OFF** — cuts power to the fan entirely via MOSFET for true natural-convection conditions
4. Add test temperatures using **+ Add** (e.g. 40, 50, 60, 70 °C)
5. Set soak time (how long to hold each temperature once stable, default 60 s)
6. Optionally enter a Run ID and Heatsink ID, then click **▶ Start CSV** to begin logging
7. Click **▶ Start Test** — the system automatically steps through each temperature
8. When complete, download:
   - **Raw CSV**: full telemetry during the test (downloaded via Stop/Download CSV)
   - **Results CSV**: one row per temperature with EqPWM, Power, R_th, k, humidity

> **Tip:** Start CSV recording before starting the test to capture the full warm-up and all transitions.

---

## Understanding the Results CSV

| Column | Meaning |
|---|---|
| SP_degC | Setpoint temperature |
| Fan_cond | Fan condition: ON or OFF |
| Temp_actual | Measured heatsink base temperature at equilibrium |
| Ambient_degC | Room temperature entered before the test |
| EqPWM | Equilibrium PWM (0–255) — heater duty cycle at thermal balance |
| Power_W | Heater power consumption (W) at equilibrium |
| R_th (°C/W) | Thermal resistance — lower is better cooling |
| k (W/°C) | Cooling coefficient |
| Humidity_pct | Ambient relative humidity at time of step (if sensor connected, else blank) |

---

## Troubleshooting

| Symptom | Fix |
|---|---|
| `ModuleNotFoundError: serial` | Use `start.bat` instead of running `python server.py` directly |
| Cannot connect to COM port | Check Device Manager; try a different USB cable; replug the ESP32 |
| Connecting… hangs indefinitely | Unplug and replug the USB cable; restart the server |
| Temperature reads 0 | Check thermocouple wiring (SPI pins 11/12/13) |
| Power reads 0 V / 0 A | Check INA226 wiring (I²C 0x41, SDA=15, SCL=16) |
| Pressure reads nothing | Check SDP510 wiring (I²C 0x40, SDA=15, SCL=16); `Wire.setTimeOut(200)` is set in firmware for this sensor's clock stretching |
| Presets not saving | Ensure the `tools/web_gui` folder is writable |
| R_th shows NaN | INA226 not connected — power readings are 0, causing divide-by-zero; check INA226 wiring |

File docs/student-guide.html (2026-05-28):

# HeatsinkLab Wind Tunnel

Student Operating Guide · Thermal Characterisation of Heatsinks

⚠ Safety — read before touching anything

- The ceramic heater element and copper spreader plate reach high temperatures during a test. Never touch the copper plate during or after a test — it stays hot for several minutes after shutdown.
- Never turn on the lab power supply until the very last step. All cables must be connected first.
- If the temperature on screen climbs unexpectedly or the system behaves oddly, click Stop immediately and call the lab supervisor.

1

## Hardware Setup

Follow these steps every time you set up the wind tunnel for a new test session.

1

### Mount the heatsink onto the heater module

Clip the heatsink under test firmly onto the copper spreader plate on the heater module. Press it flat — a loose heatsink gives inaccurate results.

Installing heatsink onto heater module

Clip the heatsink onto the copper plate

Heatsink correctly installed

Heatsink fully seated — check it is flush

2

### Insert the heater module into the wind tunnel

Slide the heater module into the opening in the wind tunnel. Route the heater wire harness out through the side cutout in the plexiglass channel.

Heater module placed in wind tunnel

Heater module in position — wire harness exits through the side

3

### Insert and connect the thermocouple

Push the thermocouple probe firmly all the way into the drilled hole in the copper plate. It must be fully seated to read temperature accurately.

Then connect the other end of the thermocouple cable to the MAX6675 thermocouple module on the PCB. The module has a small two-pin terminal block — insert the two thermocouple wires (one per terminal) and tighten the screws.

Polarity matters: the negative wire (usually red on a K-type thermocouple) goes to the − terminal; the positive wire goes to the + terminal. If the temperature reads 0 °C or jumps erratically after connecting, swap the two wires.

Inserting thermocouple into copper plate

Insert probe into the drilled hole

Thermocouple fully inserted

Thermocouple fully seated

4

### Mount the PCB

Place the control PCB onto the heater plate module.

Important: Place the isolating pad between the metal frame and the PCB before setting it down. Skipping this can cause a short circuit.

PCB mounted onto heater plate module with isolating pad

PCB placed with isolating pad underneath — check pad is visible

5

### Connect the pressure sensor cable to the sensor

The cable connector is keyed with a white tape marker. Match the white tape on the cable to the white tape on the pressure sensor — direction matters.

Pressure sensor cable before connection — white tape alignment

Align white tape marks before connecting

Pressure sensor cable correctly connected

Cable correctly connected to sensor

6

### Connect the pressure sensor tubes to the wind tunnel

The silicone tubes are colour-coded. Match each tube colour to the corresponding port on the wind tunnel.

Pressure sensor tubes connected to wind tunnel

Tubes connected to wind tunnel ports

Other view of colour-coded tubes

Match colours — both ends colour-coded

7

### Connect the pressure sensor cable to the PCB

Plug the P1 connector into the P1 socket on the PCB. The white tape marker must face the same direction on both ends.

P1 cable ready to connect to PCB — white tape alignment

P1 to P1 — align white tape on both connectors

P1 cable correctly connected to PCB

P1 cable correctly connected

8

### Connect the heater plate cable to the PCB

The heater plate wire harness plugs into the matching connector on the PCB. Press it in until it clicks.

Heater plate cable before connection

Heater plate cable ready to plug in

Heater plate cable correctly connected to PCB

Heater plate cable correctly connected

9

### Connect the motor (fan) cable to the PCB

The fan motor cable also uses the white tape alignment rule. M1 on the cable connects to M1 on the PCB.

Motor cable — white tape alignment, M1 to M1

M1 to M1 — align white tape

Motor cable correctly connected

Motor cable correctly connected

10

### Connect the humidity sensor cable to the PCB

Humidity sensor cable correctly connected to PCB

Humidity sensor cable connected

11

### Verify all connectors

Step back and look at the PCB. Every connector should be fully seated with no loose cables. Compare with the photo below.

All sensor cables correctly connected — full view

All connectors seated — your PCB should look like this

12

### Verify lab power supply voltage

Turn on the lab power supply briefly and confirm the display reads 12 V. Then turn it off again — do not connect the power cable while the supply is live.

Lab power supply — confirm 12 V then turn off

Confirm 12 V → turn supply OFF before proceeding

13

### Connect the power cable to the PCB

With the power supply off, plug the power cable into the PCB power connector.

Installing power cable to PCB

Plug power cable into PCB

Power cable installed — USB position visible

Power cable installed

14

### Connect the USB-C cable to the ESP32

The USB-C port is on the ESP32 board mounted on the PCB. Connect the cable from the bench to the ESP32.

USB-C cable connected to ESP32

USB-C cable connected to ESP32

15

### Connect USB-C to the PC, then turn on the power supply

Plug the other end of the USB-C cable into the lab PC.

Only now switch on the lab power supply. Powering the rig is always the final step.

USB-C into PC — then turn on lab power

USB into PC → then power supply ON (last step)

2

## Software Guide

1

### Launch the software

Double-click the HEATSINK TESTER shortcut on the lab PC desktop. A browser tab opens automatically.

Lab PC desktop with HEATSINK TESTER shortcut

Find the HEATSINK TESTER shortcut on the desktop

Close-up of HEATSINK TESTER icon

Double-click this shortcut

HeatsinkLab GUI open in browser — disconnected state

The GUI opens at localhost:8765 — three setup sections are visible

2

### Refresh the port list

After plugging in the USB cable, click the ⟳ refresh button next to the port dropdown. The ESP32 will appear as a new COM port in the list.

Port row — refresh button highlighted

Press ⟳ to refresh the COM port list

3

### Select the COM port

Open the port dropdown and select the entry labelled "COM3 — USB Serial Device". The number may be different on your PC — pick the USB Serial Device entry.

Port dropdown open — COM3 USB Serial Device highlighted

Select the USB Serial Device entry (COM number may differ)

4

### Click Connect

With the COM port selected, click Connect. Wait a few seconds until the status shows:

✅ Connected - Device OK · Device verified — ready to test.

COM port selected — ready to connect

COM3 selected — click Connect

Device connected and verified — full wizard visible

Green badge confirms connection — configure your test in sections 2 and 3 below

5

### Enter the Heatsink ID

In the Heatsink ID field (section 2), type the code written on your heatsink sample — for example HS-01-fin-array. This label is saved in the results file so you can identify the data later.

Refer to the screenshot above — the Heatsink ID field is directly below the connection panel.

6

### Set the temperature range

In the Test Configuration panel (section 3), enter:

Field | Meaning | Example
Start (°C) | Lowest test temperature | 40
Stop (°C) | Highest test temperature | 80
Step (°C) | Gap between temperature steps | 10

The preview chips below the fields (e.g. 40°C 50°C 60°C 70°C 80°C) show exactly which temperatures will be tested.

7

### Select wind speeds

Tick the fan speed percentages to include in the test:

Option | Meaning
Fan OFF | Natural convection — fan motor fully de-energised
0 % … 100 % | Forced convection at that fan speed

You can tick multiple speeds — the system will run a full temperature sweep at each selected speed automatically.

8

### Start the test

Click the large ▶ START TEST button at the bottom of the page. The system takes over completely from this point.

A Test in Progress panel appears with live readouts:

Display | Meaning
Temperature | Current heatsink base temperature (°C)
Setpoint | Target temperature the system is heating toward
Power (W) | Heater power consumption
Eq. PWM | Heater duty cycle converging to equilibrium
R_th (°C/W) | Thermal resistance — lower is better cooling

Test in progress — live data panel and chart

Test running — watch the live panel and chart; do not touch anything

9

### Wait — do not touch anything

The system works through each temperature step automatically:

1. Heats to the target temperature
2. Waits until temperature is stable (±0.5 °C)
3. Holds for the soak period
4. Records the result
5. Moves to the next step automatically

Typical test duration: 10–30 minutes depending on the number of steps and fan speeds selected.

10

### Download the results

When all steps are complete, a Results table appears at the bottom of the page. Click ↓ Results CSV to save the summary to your PC.

Also click ↓ Raw CSV if your instructor asks for the full telemetry log.

Results table with Results CSV and Raw CSV buttons

Results table — click ↓ Results CSV to download

11

### Remove heatsink and repeat

1. Wait for the temperature readout to drop below 35 °C before handling any components.
2. Unclip the tested heatsink from the copper plate.
3. Mount the next heatsink (back to Part 1, Step 1).
4. Return to Part 2, Step 5 — enter the new Heatsink ID and start the next test.

Do not disconnect the USB or restart the software between back-to-back tests in the same session.

## 🔧 Troubleshooting

Symptom | What to try
COM port doesn't appear in the dropdown after plugging in USB | Press the ⟳ refresh button; try a different USB port on the PC
"Connecting…" hangs indefinitely | Unplug and replug the USB cable; close and reopen the browser tab
Temperature reads 0 °C | Check the thermocouple plug is fully seated in the PCB connector
Power reads 0 W | Check the heater plate cable connector on the PCB
Pressure reads nothing | Check the P1 cable at both ends — white tape must align on both connectors
R_th shows NaN | Power reading is 0 (divide by zero) — see "Power reads 0 W" above
HEATSINK TESTER shortcut does nothing | Call the lab supervisor — the server may need to be restarted

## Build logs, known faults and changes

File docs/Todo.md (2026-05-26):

# Todo

## Hardware

- [ ] **Documentation** — complete hardware component list and datasheets
- [ ] **Architecture** — all sensors should be easily implementable; string output updated automatically when new sensors are added
    - [ ] **Implementation** of humidity sensor
        - [x] EZO-HUM I²C probe implemented and tested
        - [ ] Make expandable for additional humidity sensors
    - [x] **Implementation** of temperature sensor
        - [x] MAX6675 K-type thermocouple implemented and tested
        - [ ] Make expandable (inlet/outlet air temp sensors)
    - [x] **Implementation** of pressure sensor
        - [x] Sensirion SDP510 differential pressure implemented (replaced SDP2000-L analog)
        - [ ] Second pressure channel pending hardware
    - [ ] **Implementation** of airflow / anemometer sensor
        - [ ] Select sensor (hot-wire, Pitot, or ultrasonic)
        - [ ] Implement and test
- [x] **Architecture** — firmware telemetry string is read by server.py even as new sensors are added
    - [x] ExtSensorRegistry provides named slots — backend TELEM_RE regex accepts new named fields
- [ ] **Sensor validation** — test INA226 power measurement accuracy under load; investigate possible power losses through MOSFET resistance

## PCB

- [ ] **Design** PCB to replace dev-board wiring
    - [ ] Define standard expansion connector type and pinout (power, GND, data lines)
    - [ ] Reserve at least 2 spare expansion headers for future sensors
    - [ ] Document connector electrical limits (voltage, current, max sensor load)
    - [ ] Create sensor slot map (I²C, SPI, analog, UART) with address-conflict rules
    - [ ] Add jumper / DIP options for configurable I²C addressing
    - [ ] Add test points for power rails and sensor data lines
    - [ ] Define software sensor-configuration table format (type, bus, address, label)
    - [ ] Validate full expansion flow with one mock sensor before PCB release
    - [ ] Implement PCB and verify all connections

## Software — Firmware (`src/`)

- [x] Refactor serial communication into SerialProtocol.cpp
- [x] Refactor sensor reads into SensorManager.cpp
- [x] Modular architecture with classes (PIDController, SensorManager, ExtSensorRegistry)
- [x] SMART mode: PID until stable, then lock equilibrium PWM
- [x] SMART HOLD: fix stuck-on-SP-change bug
- [x] INA226 power monitoring integrated into telemetry
- [x] SDP510 differential pressure integrated into telemetry
- [x] EZO-HUM humidity probe integrated into telemetry
- [x] Fan power MOSFET (GPIO 10) for complete fan cut-off
- [x] FANPWR serial command (`SET FANPWR ON/OFF`)
- [x] Thermocouple fault detection → immediate heater cut
- [x] Stuck-sensor watchdog → heater cut

## Software — Backend (`tools/web_gui/server.py`)

- [x] FastAPI + WebSocket server on port 8765
- [x] TELEM_RE regex parses all telemetry fields including sensors
- [x] CSV logger with schema_version header (current: v4)
- [x] Humidity and pressure fields in CSV_FIELDS
- [x] Pressure zero / tare endpoint (`/api/pressure_tare`)
- [x] Ambient temperature endpoint (`/api/ambient`)
- [x] Virtual MCU simulator (VIRTUAL port)
- [x] Fan power state tracked in VirtualMCU
- [x] Run ID and Heatsink ID in CSV header metadata
- [ ] Post-test auto shutdown (`SET RUN OFF` on test completion) — **P0 safety item**
- [ ] Guided connection wizard with handshake progress indicator
- [ ] Startup sensor health check (INA226 + thermocouple validation)

## Software — Frontend (`tools/web_gui/static/index.html`)

- [x] Real-time Chart.js dual-axis graph (temperature + PWM)
- [x] PID parameter tuning sliders
- [x] AUTO / MANUAL / SMART mode selection
- [x] INA226 current, voltage, power readout
- [x] Tester mode with automated temperature stepping (SMART mode)
- [x] Tester: Fan ON / Fan OFF condition selector (uses GPIO 10 MOSFET)
- [x] Tester: per-temperature fan and condition recorded in Results CSV
- [x] Tester: ambient temperature auto-fill from main panel
- [x] Tester: humidity_pct column in Results CSV
- [x] Results table with EqPWM, Power_W, R_th, k per step
- [x] Expert / Student mode toggle
- [x] Performance metrics (rise time, settle time, overshoot, IAE)
- [x] Graph cursor / crosshair probe tool
- [x] CSV column customisation dialog with Power Query formula
- [x] Phase markers (📌 Marker button → chart + CSV annotation)
- [x] Presets (save / load / delete named configurations)
- [x] Pressure sensor tare / reset zero UI
- [x] Run ID and Heatsink ID fields (mirrored between Normal and Tester panels)
- [ ] Temperature range / batch entry (start, stop, step → generate list) — **P1**
- [ ] Auto result download on test completion — **P1**
- [ ] Safety layer: persistent SAFE / RUNNING / FAULT status indicator — **P0**
- [ ] Post-test auto shutdown UI confirmation — **P0**
- [ ] Guided connection wizard — **P1**
- [ ] Startup sensor health check display — **P1**

## Release / Deployment

- [ ] Dual-file release build: GUI installer (.bat / .exe) + pre-compiled firmware binary (.bin)
- [ ] Version number in GUI footer and firmware CFG output for mismatch detection
- [ ] Lab technician setup guide (no dev tools required)

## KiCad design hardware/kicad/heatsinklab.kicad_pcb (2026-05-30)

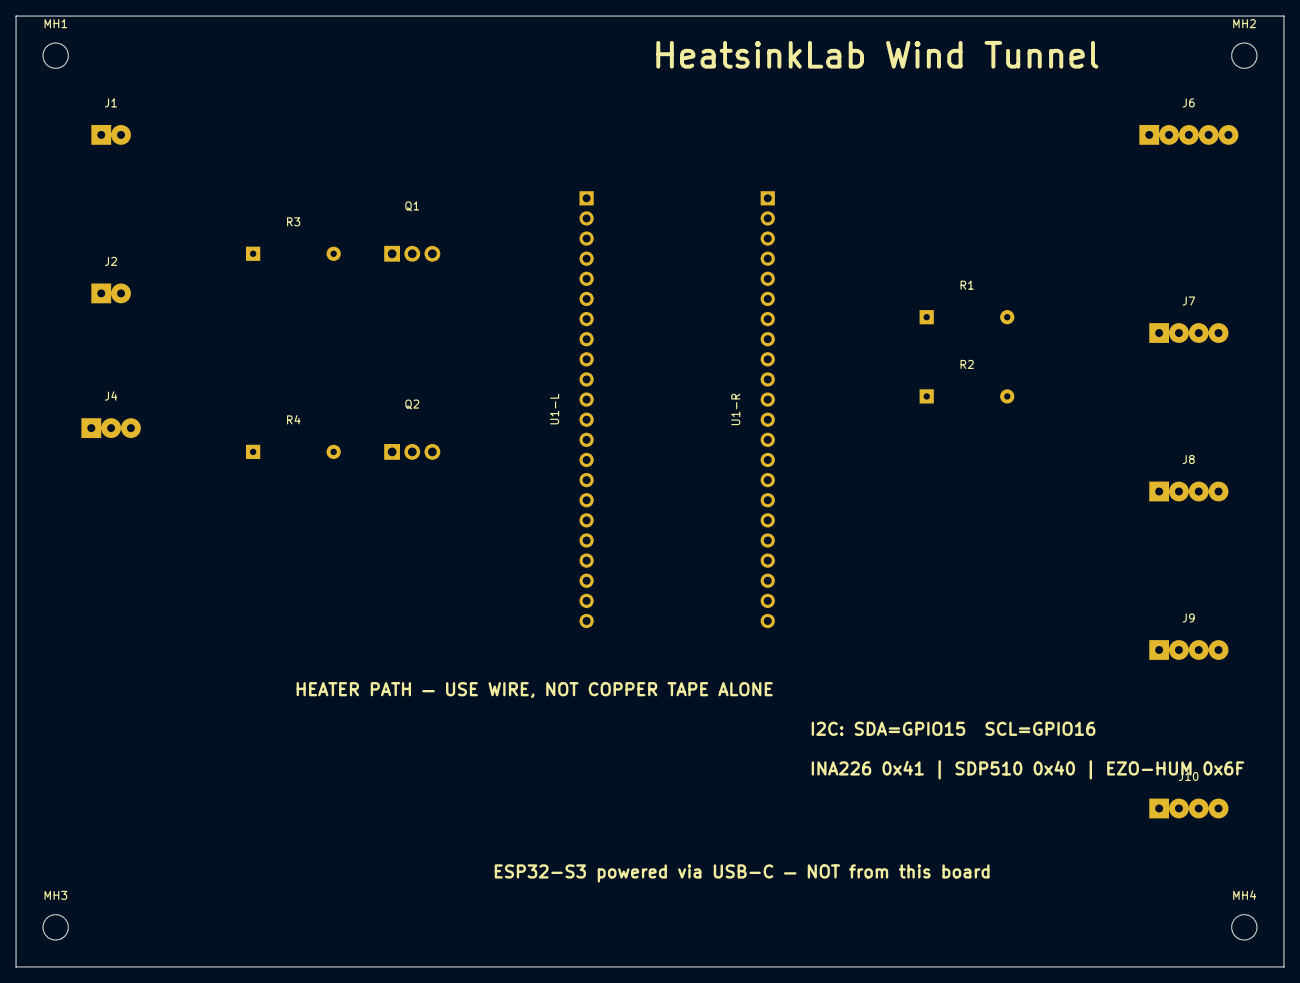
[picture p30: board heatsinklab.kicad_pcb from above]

Board: 2 copper layers, 160.0 x 120.0 mm, 20 parts (0 on the bottom side), 11 nets, no tracks yet.

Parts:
J1: PWR_IN 12V; JST_XH_B2B-XH-A_1x02_P2.50mm_Vertical
J2: HEATER_OUT; JST_XH_B2B-XH-A_1x02_P2.50mm_Vertical
J4: FAN 12V/GND/PWM; JST_XH_B3B-XH-A_1x03_P2.50mm_Vertical
J6: THERMO MAX6675; JST_XH_B5B-XH-A_1x05_P2.50mm_Vertical
J7: INA226 0x41; JST_XH_B4B-XH-A_1x04_P2.50mm_Vertical
J8: SDP510 0x40; JST_XH_B4B-XH-A_1x04_P2.50mm_Vertical
J9: EZO-HUM 0x6F; JST_XH_B4B-XH-A_1x04_P2.50mm_Vertical
J10: EXT1 Future; JST_XH_B4B-XH-A_1x04_P2.50mm_Vertical
MH1, MH2, MH3, MH4: MountingHole; MountingHole_3.2mm_M3
Q1: IRLZ44N Heater; TO-220-3_Vertical
Q2: IRLZ44N Fan; TO-220-3_Vertical
R1: 4.7k SDA; R_Axial_DIN0207_L6.3mm_D2.5mm_P10.16mm_Horizontal
R2: 4.7k SCL; R_Axial_DIN0207_L6.3mm_D2.5mm_P10.16mm_Horizontal
R3, R4: 10k Gate GND; R_Axial_DIN0207_L6.3mm_D2.5mm_P10.16mm_Horizontal
U1-L: ESP32-S3-DevKitC-1 Left; PinHeader_1x22_P2.54mm_Vertical
U1-R: ESP32-S3-DevKitC-1 Right; PinHeader_1x22_P2.54mm_Vertical

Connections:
+3.3V: J6.1, J7.1, J8.1, J9.1, J10.1, R1.1, R2.1, U1-L.1, U1-L.2
FAN_OUT_P: J4.1, Q2.2
GND: J1.2, J2.2, J4.2, J6.2, J7.2, J8.2, J9.2, J10.2, Q1.3, Q2.3, R3.2, R4.2, U1-L.22, U1-R.1, U1-R.21, U1-R.22
GPIO4_HEAT: Q1.1, R3.1, U1-L.4
GPIO5_FPWM: J4.3, U1-L.5
GPIO10_FEN: Q2.1, R4.1, U1-L.16
I2C_SCL: J7.4, J8.4, J9.4, R2.2, U1-L.9
I2C_SDA: J7.3, J8.3, J9.3, R1.2, U1-L.8
SPI_CS: J6.4, U1-L.18
SPI_MISO: J6.3, U1-L.17
SPI_SCK: J6.5, U1-L.19

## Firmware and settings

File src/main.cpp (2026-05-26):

#include <Arduino.h>
#include <math.h>
#include "SystemState.h"
#include "PIDController.h"
#include "SensorManager.h"
#include "SerialProtocol.h"
#include "ExtSensorRegistry.h"

// ── Pin definitions ────────────────────────────────────────────────────────────
static const int PIN_HEATER_MOSFET = 4;
static const int PIN_FAN_PWM       = 5;
static const int PIN_FAN_POWER     = 10;  // MOSFET gate — HIGH = fan powered, LOW = fan fully off

// ── PWM channels ──────────────────────────────────────────────────────────────
static const int HEATER_PWM_CH  = 0;
static const int FAN_PWM_CH     = 1;
static const int PWM_FREQ       = 500;
static const int PWM_RESOLUTION = 8;

// ── Control timing ─────────────────────────────────────────────────────────────
static const uint32_t CONTROL_PERIOD_MS = 500;
static uint32_t lastControlMs = 0;

// ── Thermocouple accuracy constant (used in SMART mode) ──────────────────────
static const float THERMOCOUPLE_ACCURACY_C = 0.25f;

// ── SMART mode state ───────────────────────────────────────────────────────────
static const uint16_t SMART_PWM_AVG_WINDOW = 40;  // 20 s at 0.5 s period
static float    smartPwmHistory[SMART_PWM_AVG_WINDOW];
static uint16_t smartPwmHistCount = 0;
static uint16_t smartPwmHistIndex = 0;
static uint16_t smartStableCount  = 0;
static uint16_t smartDriftCount   = 0;
static float    lastSmoothForSlope = NAN;
static float    pwmDitherAccumulator = 0.0f;

// ── PWM slew-rate state ────────────────────────────────────────────────────────
static int lastPWM = 0;

// ── Extension sensor slot indices ─────────────────────────────────────────────
static int8_t humSlot      = -1;
static int8_t humTempSlot  = -1;
static int8_t deltaP1Slot  = -1;  // raw pressure ch1, Pa
static int8_t deltaP1FSlot = -1;  // EMA-filtered pressure ch1, Pa
static int8_t deltaP2Slot  = -1;  // raw pressure ch2, Pa
static int8_t deltaP2FSlot = -1;  // EMA-filtered pressure ch2, Pa

// ── Global instances ───────────────────────────────────────────────────────────
SystemState     sys;
PIDController   pid(8.0f, 0.06f, 0.0f);

// (sensors and extSensors are defined in their respective .cpp files)

// ── System state defaults ──────────────────────────────────────────────────────
static void initSysDefaults() {
    sys.pidKp              = 8.0f;
    sys.pidKi              = 0.06f;
    sys.pidKd              = 0.0f;
    sys.pidBias            = 0.0f;
    sys.setpointBias       = 0.0f;
    sys.setpoint           = 70.0f;
    sys.emaAlpha           = 0.25f;
    sys.maxPwmStep         = 15;
    sys.fanSpeedPercent    = 0.0f;
    sys.fanPwmInverted     = false;
    sys.fanPwmApplied      = 255;
    sys.fanPowerEnabled    = true;
    sys.controlMode        = MODE_AUTO;
    sys.manualPwmTarget    = 0.0f;
    sys.controlEnabled     = true;
    sys.smartEnterCount    = 16;
    sys.smartExitCount     = 8;
    sys.smartHoldActive    = false;
    sys.smartHoldPwmTarget = 0.0f;
    sys.smartEnterProgressPct = 0.0f;
    sys.smartExitProgressPct  = 0.0f;
    sys.eqPwm              = 0.0f;
}

// ── Actuator helpers ───────────────────────────────────────────────────────────

static int fanPercentToRaw(float percent) {
    float clamped = constrain(percent, 0.0f, 100.0f);
    float duty = clamped / 100.0f;
    if (!sys.fanPwmInverted) duty = 1.0f - duty;
    return constrain((int)lroundf(255.0f * duty), 0, 255);
}

void setFanSpeedPercent(float percent) {
    sys.fanSpeedPercent = constrain(percent, 0.0f, 100.0f);
    int raw = fanPercentToRaw(sys.fanSpeedPercent);
    if (sys.controlEnabled) {
        ledcWrite(FAN_PWM_CH, raw);
        sys.fanPwmApplied = raw;
    } else {
        ledcWrite(FAN_PWM_CH, 0);
        sys.fanPwmApplied = 0;
    }
}

void applyFanPower() {
    digitalWrite(PIN_FAN_POWER, sys.fanPowerEnabled ? HIGH : LOW);
}

static void setPWM(int duty) {
    duty = constrain(duty, 0, 255);
    ledcWrite(HEATER_PWM_CH, duty);
}

// ── PID helpers ────────────────────────────────────────────────────────────────

void applyPidTunings() {
    pid.setTunings(sys.pidKp, sys.pidKi, sys.pidKd);
    pid.setBias(sys.pidBias);
    pid.reset();
}

// ── SMART mode helpers ─────────────────────────────────────────────────────────

void resetSmartState() {
    sys.smartHoldActive       = false;
    sys.smartHoldPwmTarget    = 0.0f;
    sys.smartEnterProgressPct = 0.0f;
    sys.smartExitProgressPct  = 0.0f;
    smartStableCount          = 0;
    smartDriftCount           = 0;
    smartPwmHistCount         = 0;
    smartPwmHistIndex         = 0;
    pwmDitherAccumulator      = 0.0f;
    lastSmoothForSlope        = NAN;
}

static void pushSmartPwmSample(float pwm) {
    smartPwmHistory[smartPwmHistIndex] = pwm;
    smartPwmHistIndex = (uint16_t)((smartPwmHistIndex + 1) % SMART_PWM_AVG_WINDOW);
    if (smartPwmHistCount < SMART_PWM_AVG_WINDOW) smartPwmHistCount++;
}

static float getSmartPwmAverage() {
    if (smartPwmHistCount == 0) return 0.0f;
    float sum = 0.0f;
    for (uint16_t i = 0; i < smartPwmHistCount; i++) sum += smartPwmHistory[i];
    return sum / (float)smartPwmHistCount;
}

static int ditheredPwmFromTarget(float targetPwm) {
    float clamped = constrain(targetPwm, 0.0f, 255.0f);
    int base = (int)floorf(clamped);
    pwmDitherAccumulator += clamped - (float)base;
    int pwm = base;
    if (pwmDitherAccumulator >= 1.0f) { pwm++; pwmDitherAccumulator -= 1.0f; }
    return constrain(pwm, 0, 255);
}

static int limitPWMChange(int pwm, int maxStep) {
    if (pwm > lastPWM + maxStep) pwm = lastPWM + maxStep;
    if (pwm < lastPWM - maxStep) pwm = lastPWM - maxStep;
    lastPWM = pwm;
    return pwm;
}

// ── setup ──────────────────────────────────────────────────────────────────────

void setup() {
    Serial.begin(115200);
    delay(500);

    initSysDefaults();
    SerialProtocol::loadConfig();  // overlay NVS values onto sys

    sensors.begin(sys.emaAlpha);

    ledcSetup(HEATER_PWM_CH, PWM_FREQ, PWM_RESOLUTION);
    ledcAttachPin(PIN_HEATER_MOSFET, HEATER_PWM_CH);
    ledcSetup(FAN_PWM_CH, PWM_FREQ, PWM_RESOLUTION);
    ledcAttachPin(PIN_FAN_PWM, FAN_PWM_CH);

    setPWM(0);
    setFanSpeedPercent(sys.fanSpeedPercent);
    pinMode(PIN_FAN_POWER, OUTPUT);
    applyFanPower();
    applyPidTunings();
    resetSmartState();

    // ── Register extension sensors ────────────────────────────────────────
    //   int8_t airspeedSlot = extSensors.registerSensor("AIRSPEED", "m/s");
    //   int8_t deltaP1Slot  = extSensors.registerSensor("DELTA_P1", "Pa");
    //   int8_t deltaP2Slot  = extSensors.registerSensor("DELTA_P2", "Pa");

    // EZO-HUM humidity probe — I2C init handled in sensors.begin()
    humSlot      = extSensors.registerSensor("HUMIDITY", "%");
    humTempSlot  = extSensors.registerSensor("HUM_TEMP", "C");

    // Differential pressure sensors — ADC init handled in sensors.begin()
    deltaP1Slot  = extSensors.registerSensor("DELTA_P1",  "Pa");
    deltaP1FSlot = extSensors.registerSensor("DELTA_P1F", "Pa");
    deltaP2Slot  = extSensors.registerSensor("DELTA_P2",  "Pa");
    deltaP2FSlot = extSensors.registerSensor("DELTA_P2F", "Pa");
    // ─────────────────────────────────────────────────────────────────────

    Serial.println("System started");
    Serial.println("Commands: GET, SET KP <v>, SET KI <v>, SET KD <v>, SET BIAS <v>, SET SPBIAS <v>, SET SP <v>, SET ALPHA <v>, SET MAXSTEP <v>, SET ENTERCNT <1..400>, SET EXITCNT <1..400>, SET FAN <0..100>, SET FANINV <0|1>, SET FANPWR <ON|OFF>, SET MODE <AUTO|MANUAL|SMART>, SET MANPWM <0..255>, SET RUN <ON|OFF>");
    SerialProtocol::printConfig();
}

// ── loop ───────────────────────────────────────────────────────────────────────

void loop() {
    SerialProtocol::processCommands();

    uint32_t now = millis();
    if ((now - lastControlMs) < CONTROL_PERIOD_MS) return;
    lastControlMs = now;

    // ── Read all sensors (EZO-HUM cycle handled inside SensorManager) ───────
    CoreSensorData sd = sensors.read();

    // ── Update extension sensor slots ────────────────────────────────────
    if (humSlot      >= 0) extSensors.update(humSlot,      sd.humidityPct);
    if (humTempSlot  >= 0) extSensors.update(humTempSlot,  sd.humTemp);
    if (deltaP1Slot  >= 0) extSensors.update(deltaP1Slot,  sd.deltaP1Raw);
    if (deltaP1FSlot >= 0) extSensors.update(deltaP1FSlot, sd.deltaP1Filt);
    if (deltaP2Slot  >= 0) extSensors.update(deltaP2Slot,  sd.deltaP2Raw);
    if (deltaP2FSlot >= 0) extSensors.update(deltaP2FSlot, sd.deltaP2Filt);
    // ─────────────────────────────────────────────────────────────────────

    // ── Thermocouple fault: cut heater immediately ─────────────────────────
    if (isnan(sd.filteredTemp)) {
        setPWM(0);
        ledcWrite(FAN_PWM_CH, 0);
        sys.fanPwmApplied = 0;
        pid.reset();
        resetSmartState();
        sensors.resetEma();
        Serial.println("Temp read error -> heater OFF (NaN/out of range)");
        return;
    }

    if (sd.tempStuck) {
        setPWM(0);
        ledcWrite(FAN_PWM_CH, 0);
        sys.fanPwmApplied = 0;
        pid.reset();
        resetSmartState();
        sensors.resetEma();
        sensors.resetStuck();
        Serial.println("Thermocouple STUCK detected -> heater OFF + PID reset");
        delay(500);
        return;
    }

    // ── Derived quantities ────────────────────────────────────────────────
    float effectiveSetpoint = constrain(sys.setpoint + sys.setpointBias, -20.0f, 400.0f);
    float error             = effectiveSetpoint - sd.smoothTemp;
    float absError          = fabsf(error);
    float absErrorMinusAcc  = max(0.0f, absError - THERMOCOUPLE_ACCURACY_C);

    float slope = 0.0f;
    if (!isnan(lastSmoothForSlope)) {
        slope = (sd.smoothTemp - lastSmoothForSlope) / ((float)CONTROL_PERIOD_MS / 1000.0f);
    }
    float absSlope = fabsf(slope);
    lastSmoothForSlope = sd.smoothTemp;

    const float smartEnterErrC   = THERMOCOUPLE_ACCURACY_C * 2.0f;  // 0.50 °C
    const float smartEnterSlopeCps = 0.25f;
    const float smartExitErrC    = THERMOCOUPLE_ACCURACY_C * 4.0f;  // 1.00 °C

    // ── Control law ───────────────────────────────────────────────────────
    int pwm = 0;

    if (!sys.controlEnabled) {
        setPWM(0);
        ledcWrite(FAN_PWM_CH, 0);
        sys.fanPwmApplied = 0;
        sys.smartHoldActive       = false;
        smartStableCount          = 0;
        smartDriftCount           = 0;
        sys.smartEnterProgressPct = 0.0f;
        sys.smartExitProgressPct  = 0.0f;
    } else {
        setFanSpeedPercent(sys.fanSpeedPercent);

        if (sys.controlMode == MODE_MANUAL) {
            pwm = ditheredPwmFromTarget(sys.manualPwmTarget);
            sys.smartHoldActive       = false;
            sys.smartEnterProgressPct = 0.0f;
            sys.smartExitProgressPct  = 0.0f;
            lastPWM = pwm;

        } else if (sys.controlMode == MODE_AUTO) {
            pwm = (int)pid.calculate(effectiveSetpoint, sd.smoothTemp);
            pwm = limitPWMChange(pwm, sys.maxPwmStep);
            sys.smartHoldActive       = false;
            smartStableCount          = 0;
            smartDriftCount           = 0;
            sys.smartEnterProgressPct = 0.0f;
            sys.smartExitProgressPct  = 0.0f;

        } else {
            // ── SMART mode ─────────────────────────────────────────────────
            if (!sys.smartHoldActive) {
                pwm = (int)pid.calculate(effectiveSetpoint, sd.smoothTemp);
                pwm = limitPWMChange(pwm, sys.maxPwmStep);
                pushSmartPwmSample((float)pwm);

                bool isStable = (absErrorMinusAcc <= smartEnterErrC) && (absSlope <= smartEnterSlopeCps);
                if (isStable) {
                    if (smartStableCount < sys.smartEnterCount) smartStableCount++;
                } else {
                    if (smartStableCount > 0) smartStableCount--;
                }
                sys.smartEnterProgressPct = min(100.0f, 100.0f * ((float)smartStableCount / (float)sys.smartEnterCount));
                sys.smartExitProgressPct  = 0.0f;

                if (smartStableCount >= sys.smartEnterCount && smartPwmHistCount >= 10) {
                    sys.smartHoldPwmTarget = getSmartPwmAverage();
                    sys.smartHoldActive    = true;
                    smartDriftCount        = 0;
                    pwmDitherAccumulator   = 0.0f;
                    sys.smartEnterProgressPct = 100.0f;
                    Serial.printf("SMART ENTER HOLD | HOLDPWM: %.2f | ERR: %.2f C | SLOPE: %.3f C/s\n",
                                  sys.smartHoldPwmTarget, error, slope);
                }
            } else {
                pwm = ditheredPwmFromTarget(sys.smartHoldPwmTarget);
                lastPWM = pwm;

                if (absErrorMinusAcc >= smartExitErrC) {
                    smartDriftCount++;
                } else {
                    smartDriftCount = 0;
                }
                sys.smartEnterProgressPct = 100.0f;
                sys.smartExitProgressPct  = min(100.0f, 100.0f * ((float)smartDriftCount / (float)sys.smartExitCount));

                if (smartDriftCount >= sys.smartExitCount) {
                    sys.smartHoldActive       = false;
                    smartStableCount          = 0;
                    smartDriftCount           = 0;
                    smartPwmHistCount         = 0;
                    smartPwmHistIndex         = 0;
                    sys.smartEnterProgressPct = 0.0f;
                    sys.smartExitProgressPct  = 0.0f;
                    pid.reset();
                    Serial.printf("SMART EXIT HOLD -> PID | ERR: %.2f C | SLOPE: %.3f C/s\n", error, slope);
                }
            }
        }

        setPWM(pwm);
    }

    // ── Equilibrium PWM estimate ──────────────────────────────────────────
    if (absSlope < 0.3f && sys.controlEnabled) {
        sys.eqPwm = 0.05f * (float)pwm + 0.95f * sys.eqPwm;
    }

    // ── Telemetry ─────────────────────────────────────────────────────────
    float pTerm = 0.0f, iTerm = 0.0f, dTerm = 0.0f, pidOut = 0.0f;
    pid.getLastTerms(pTerm, iTerm, dTerm, pidOut);

    const char *stateText = "PID";
    if (sys.controlMode == MODE_MANUAL) {
        stateText = "MANUAL";
    } else if (sys.controlMode == MODE_SMART && sys.smartHoldActive) {
        stateText = "HOLD";
    }

    SerialProtocol::emitTelemetry(sd, pwm, pTerm, iTerm, dTerm, pidOut, stateText);
}

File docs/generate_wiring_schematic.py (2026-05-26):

"""
Generate wiring_schematic.docx for the ESP32-S3 Heater Plate Control System.
"""

from docx import Document
from docx.shared import Pt, RGBColor, Inches, Cm, Twips
from docx.enum.text import WD_ALIGN_PARAGRAPH, WD_LINE_SPACING
from docx.enum.table import WD_TABLE_ALIGNMENT, WD_ALIGN_VERTICAL
from docx.oxml.ns import qn
from docx.oxml import OxmlElement
from docx.enum.section import WD_SECTION
import copy
from lxml import etree

import os as _os
OUTPUT = _os.path.join(_os.path.dirname(_os.path.abspath(__file__)), "wiring_schematic.docx")

# ── colour constants ────────────────────────────────────────────────────────
DARK_BLUE   = "1F4E79"   # header bar
LIGHT_BLUE  = "D5E8F0"   # table header shading
WARN_RED    = "FFE6E6"   # warning rows
ALT_GREY    = "F5F5F5"   # alternating row
WHITE       = "FFFFFF"
TEXT_WHITE  = "FFFFFF"
RED_TEXT    = "CC0000"
GREY_TEXT   = "808080"

# ── helpers ─────────────────────────────────────────────────────────────────

def set_cell_shading_and_borders(cell, fill_hex: str, add_borders: bool = False):
    """
    Apply solid background shading and optionally borders to a table cell.
    OOXML CT_TcPr ordering: tcW, gridSpan, hMerge, vMerge, tcBorders, shd, noWrap, ...
    tcBorders MUST appear before shd.
    """
    tc = cell._tc
    tcPr = tc.get_or_add_tcPr()

    # Remove any existing shd or tcBorders first to avoid duplicates
    for tag in (qn("w:shd"), qn("w:tcBorders")):
        existing = tcPr.find(tag)
        if existing is not None:
            tcPr.remove(existing)

    if add_borders:
        tcBorders = OxmlElement("w:tcBorders")
        for edge in ("top", "left", "bottom", "right"):
            el = OxmlElement(f"w:{edge}")
            el.set(qn("w:val"), "single")
            el.set(qn("w:sz"), "4")
            el.set(qn("w:space"), "0")
            el.set(qn("w:color"), "AAAAAA")
            tcBorders.append(el)
        tcPr.append(tcBorders)

    shd = OxmlElement("w:shd")
    shd.set(qn("w:val"), "clear")
    shd.set(qn("w:color"), "auto")
    shd.set(qn("w:fill"), fill_hex)
    tcPr.append(shd)


def set_cell_shading(cell, fill_hex: str):
    """Apply solid background shading to a table cell (no borders)."""
    set_cell_shading_and_borders(cell, fill_hex, add_borders=False)


def set_cell_borders(cell):
    """Not used directly — use set_cell_shading_and_borders instead."""
    pass


def cell_text(cell, text, bold=False, color_hex=None, font_size=9, italic=False):
    """Clear cell and add formatted paragraph."""
    cell.text = ""
    p = cell.paragraphs[0]
    p.alignment = WD_ALIGN_PARAGRAPH.LEFT
    run = p.add_run(text)
    run.bold = bold
    run.italic = italic
    run.font.size = Pt(font_size)
    run.font.name = "Arial"
    if color_hex:
        run.font.color.rgb = RGBColor.from_string(color_hex)
    return p


def add_section_heading(doc, text, level=1):
    """Add bold section heading in Arial 12pt dark blue."""
    p = doc.add_paragraph()
    p.paragraph_format.space_before = Pt(12)
    p.paragraph_format.space_after = Pt(4)
    run = p.add_run(text)
    run.bold = True
    run.font.size = Pt(12)
    run.font.name = "Arial"
    run.font.color.rgb = RGBColor.from_string(DARK_BLUE)
    return p


def add_sub_heading(doc, text):
    p = doc.add_paragraph()
    p.paragraph_format.space_before = Pt(8)
    p.paragraph_format.space_after = Pt(3)
    run = p.add_run(text)
    run.bold = True
    run.font.size = Pt(10)
    run.font.name = "Arial"
    run.font.color.rgb = RGBColor.from_string(DARK_BLUE)
    return p


def add_note_paragraph(doc, text):
    p = doc.add_paragraph()
    p.paragraph_format.space_before = Pt(4)
    p.paragraph_format.space_after = Pt(6)
    p.paragraph_format.left_indent = Inches(0.2)
    run = p.add_run("Note: ")
    run.bold = True
    run.italic = True
    run.font.size = Pt(9)
    run.font.name = "Arial"
    run2 = p.add_run(text)
    run2.italic = True
    run2.font.size = Pt(9)
    run2.font.name = "Arial"
    return p


def make_table(doc, headers, rows, col_widths_cm=None):
    """
    Build a styled table.
    headers: list of str
    rows: list of list of str; prefix '!' for warning row shading
    col_widths_cm: list of floats in cm
    """
    n_cols = len(headers)
    table = doc.add_table(rows=1 + len(rows), cols=n_cols)
    table.style = "Table Grid"
    table.alignment = WD_TABLE_ALIGNMENT.LEFT

    # Set column widths
    if col_widths_cm:
        for col_idx, w in enumerate(col_widths_cm):
            for cell in table.columns[col_idx].cells:
                cell.width = Cm(w)

    # Header row
    hdr_row = table.rows[0]
    for i, hdr in enumerate(headers):
        cell = hdr_row.cells[i]
        set_cell_shading_and_borders(cell, DARK_BLUE, add_borders=True)
        cell_text(cell, hdr, bold=True, color_hex=TEXT_WHITE, font_size=9)

    # Data rows
    for r_idx, row_data in enumerate(rows):
        # detect warning marker
        is_warn = False
        clean_row = []
        for cell_val in row_data:
            if cell_val.startswith("!"):
                is_warn = True
                clean_row.append(cell_val[1:])
            else:
                clean_row.append(cell_val)

        fill = WARN_RED if is_warn else (ALT_GREY if r_idx % 2 == 1 else WHITE)
        tr = table.rows[r_idx + 1]
        for c_idx, val in enumerate(clean_row):
            cell = tr.cells[c_idx]
            set_cell_shading_and_borders(cell, fill, add_borders=True)
            cell_text(cell, val, font_size=9)

    doc.add_paragraph()  # spacing after table
    return table


def set_table_no_split(table):
    for row in table.rows:
        trPr = row._tr.get_or_add_trPr()
        cantSplit = OxmlElement("w:cantSplit")
        cantSplit.set(qn("w:val"), "true")
        trPr.append(cantSplit)
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

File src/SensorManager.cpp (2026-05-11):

#include "SensorManager.h"
#include "max6675.h"
#include "INA226.h"
#include <Wire.h>
#include <math.h>

// ── Pin definitions (must match main.cpp) ─────────────────────────────────────
static const int PIN_SCK = 13;
static const int PIN_CS  = 12;
static const int PIN_SO  = 11;
static const int PIN_SDA = 15;
static const int PIN_SCL = 16;

// ── EZO-HUM constants ─────────────────────────────────────────────────────────
static const uint8_t  EZO_HUM_ADDR          = 0x6F;
static const uint32_t EZO_RESPONSE_DELAY_MS = 300;

// ── Sensor constants ──────────────────────────────────────────────────────────
static const float SUPPLY_VOLTAGE   = 12.0f;  // nominal PSU voltage used for power calc
static const float MAX_JUMP_C       = 100.0f; // glitch reject: max allowed single-tick jump
static const float STUCK_EPSILON_C  = 0.01f;  // below this delta → "same" reading
static const uint16_t STUCK_LIMIT   = 30;     // consecutive "same" ticks before stuck declared

// ── SDP510 differential pressure sensor (I2C) ────────────────────────────────
static const uint8_t SDP610_ADDR      = 0x40;  // fixed I2C address
static const float   SDP610_SCALE     = 60.0f; // counts/Pa (500 Pa range variant)
static const float   SDP610_EMA_ALPHA = 0.15f; // EMA smoothing factor

// ── Sensor objects ────────────────────────────────────────────────────────────
static MAX6675 thermocouple(PIN_SCK, PIN_CS, PIN_SO);
static INA226  ina226(0x41);  // A0 wired to VCC → address 0x41

// ── Singleton instance ────────────────────────────────────────────────────────
SensorManager sensors;

// ── Public methods ────────────────────────────────────────────────────────────

void SensorManager::begin(float emaAlphaInit) {
    _emaAlpha = emaAlphaInit;

    Wire.begin(PIN_SDA, PIN_SCL);
    Wire.setTimeOut(200);  // SDP610 clock-stretches up to 80ms; default timeout is too short

    // EZO-HUM: enable temperature output, disable dew point (sent once at boot)
    Wire.beginTransmission(EZO_HUM_ADDR);
    Wire.write("O,T,1\r");
    Wire.endTransmission();
    delay(300);
    Wire.beginTransmission(EZO_HUM_ADDR);
    Wire.write("O,Dew,0\r");
    Wire.endTransmission();
    delay(300);

    // SDP510: trigger first measurement, then read back to confirm sensor present
    Wire.beginTransmission(SDP610_ADDR);
    Wire.write(0xF1);
    uint8_t sdpErr = Wire.endTransmission();
    if (sdpErr != 0) {
        Serial.printf("SDP510 NOT FOUND – trigger error %u (check wiring SDA=15 SCL=16)\n", sdpErr);
    } else {
        // sensor will clock-stretch on requestFrom; read back first measurement
        if (Wire.requestFrom((uint8_t)SDP610_ADDR, (uint8_t)3) == 3) {
            uint8_t msb = Wire.read();
            uint8_t lsb = Wire.read();
            Wire.read();  // CRC
            int16_t raw = (int16_t)((uint16_t)(msb << 8) | lsb);
            float pa = (float)raw / SDP610_SCALE;
            _emaP1 = pa;  // seed EMA with first real reading
            Serial.printf("SDP510 OK – first reading: %.2f Pa\n", pa);
        } else {
            Serial.println("SDP510 found but read timed out – check Wire.setTimeOut()");
            _emaP1 = 0.0f;
        }
    }
    _emaP2 = 0.0f;

    _inaOk = ina226.begin();
    if (_inaOk) {
        ina226.setMaxCurrentShunt(2.0f, 0.0353f);  // 2 A max, ~35.3 mΩ shunt
        ina226.setAverage(INA226_1024_SAMPLES);
        ina226.setShuntVoltageConversionTime(INA226_8300_us);
        ina226.setBusVoltageConversionTime(INA226_8300_us);
        Serial.println("INA226 OK");
    } else {
        Serial.println("INA226 NOT FOUND – check wiring");
    }
}

void SensorManager::setEmaAlpha(float alpha) {
    _emaAlpha = alpha;
}

void SensorManager::resetEma() {
    _emaTemp = NAN;
}

void SensorManager::resetStuck() {
    _lastTempForStuck = NAN;
    _sameCount = 0;
}

CoreSensorData SensorManager::read() {
    CoreSensorData d;

    // ── INA226 ─────────────────────────────────────────────────────────────
    d.inaOk = _inaOk;
    if (_inaOk) {
        d.inaVoltage = SUPPLY_VOLTAGE;
        d.inaCurrent = ina226.getCurrent();
        d.inaPower   = d.inaVoltage * d.inaCurrent;
    } else {
        d.inaVoltage = 0.0f;
        d.inaCurrent = 0.0f;
        d.inaPower   = 0.0f;
    }

    // ── Thermocouple ───────────────────────────────────────────────────────
    float raw = thermocouple.readCelsius();
    d.rawTemp = raw;

    float filtered = applyGlitchReject(raw);
    d.filteredTemp = filtered;

    if (!isnan(filtered)) {
        d.smoothTemp = applyEma(filtered);
        d.tempStuck  = checkStuck(filtered);
    } else {
        d.smoothTemp = NAN;
        d.tempStuck  = false;
    }

    // ── EZO-HUM: read previous response if ≥300 ms have elapsed ──────────
    if (_ezoReadPending && (millis() - _ezoSendTime >= EZO_RESPONSE_DELAY_MS)) {
        Wire.requestFrom(EZO_HUM_ADDR, (uint8_t)20);
        uint8_t status = Wire.available() ? Wire.read() : 0xFF;
        char buf[24] = {};
        uint8_t idx = 0;
        if (status == 0x01) {
            while (Wire.available() && idx < sizeof(buf) - 1) {
                char c = Wire.read();
                if (c == 0 || c == '\r') break;
                buf[idx++] = c;
            }
        }
        _ezoReadPending = false;
        char *comma = strchr(buf, ',');
        if (comma) {
            *comma = '\0';
            _humidityPct = atof(buf);
            _humTemp     = atof(comma + 1);
            _ezoHumOk    = true;
        }
    }

    // ── EZO-HUM: send new read command for next tick ──────────────────────
    Wire.beginTransmission(EZO_HUM_ADDR);
    Wire.write('R');
    Wire.endTransmission();
    _ezoReadPending = true;
    _ezoSendTime    = millis();

    d.humidityPct = _humidityPct;
    d.humTemp     = _humTemp;
    d.ezoHumOk    = _ezoHumOk;

    // ── SDP610 differential pressure (I2C, clock-stretching single-shot) ──────
    Wire.beginTransmission(SDP610_ADDR);
    Wire.write(0xF1);
    Wire.endTransmission();
    if (Wire.requestFrom((uint8_t)SDP610_ADDR, (uint8_t)3) == 3) {
        uint8_t msb = Wire.read();
        uint8_t lsb = Wire.read();
        Wire.read();  // CRC — discard (factory-calibrated sensor)
        int16_t raw = (int16_t)((uint16_t)(msb << 8) | lsb);
        float pa = (float)raw / SDP610_SCALE;
        _emaP1 = SDP610_EMA_ALPHA * pa + (1.0f - SDP610_EMA_ALPHA) * _emaP1;
        d.deltaP1Raw  = pa;
        d.deltaP1Filt = _emaP1;
    } else {
        d.deltaP1Raw  = _emaP1;  // hold last good on I2C failure
        d.deltaP1Filt = _emaP1;
    }
    d.deltaP2Raw  = 0.0f;  // no second pressure channel
    d.deltaP2Filt = 0.0f;

    return d;
}

// ── Private helpers ───────────────────────────────────────────────────────────

bool SensorManager::isValidTemp(float t) const {
    if (isnan(t)) return false;
    if (t < -20.0f || t > 400.0f) return false;
    return true;
}
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

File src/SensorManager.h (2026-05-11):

#ifndef SENSORMANAGER_H
#define SENSORMANAGER_H

#include <Arduino.h>

// ── CoreSensorData ─────────────────────────────────────────────────────────────
// Snapshot of all sensor readings for one control tick.
// Returned by SensorManager::read() — stack-allocated, no heap use.
//
// ── HOW TO ADD A NEW SENSOR VALUE ─────────────────────────────────────────────
// 1. Add your field(s) below with a comment naming the sensor and bus slot.
//    Use float for measured values, bool for health/presence flags.
//
//    Example — second thermocouple (MAX6675 #2 on its own CS pin):
//        float rawTemp2;        // MAX6675 #2, SPI slot 1
//        float filteredTemp2;   // glitch-rejected
//        float smoothTemp2;     // EMA-filtered
//
//    Example — differential pressure (e.g. DLVR-L10D on I2C):
//        float deltaP1;         // channel 1, Pa
//        float deltaP2;         // channel 2, Pa
//        bool  pressureOk;      // false if sensor not found on I2C
//
//    Example — airspeed (analog/pulse anemometer):
//        float airspeed;        // m/s
//
//    Example — ambient humidity (e.g. SHT31 on I2C):
//        float humidityPct;     // %RH
//        bool  humidityOk;
//
// 2. Initialise the new field(s) to 0.0f / false in SensorManager::read()
//    before the sensor is wired, so telemetry is always well-formed.
//
// 3. Populate the field(s) in SensorManager::read() once the hardware exists.
//
// 4. Register the value with ExtSensorRegistry (setup: registerSensor,
//    loop: update) so it appears in the telemetry stream automatically.
//    OR add it to the fixed telemetry line in SerialProtocol::emitTelemetry()
//    if it is a core sensor that must always be present (like temperature).
//
// 5. Follow the full 4-step sensor pattern in CLAUDE.md for backend + CSV.
// ──────────────────────────────────────────────────────────────────────────────
struct CoreSensorData {
    // ── Thermocouple (MAX6675, SPI slot 0) ────────────────────────────────
    float rawTemp;       // direct thermocouple reading, NAN on read error
    float filteredTemp;  // glitch-rejected (>100 °C jump discarded)
    float smoothTemp;    // EMA-filtered (alpha set via SET ALPHA)

    // ── Power monitor (INA226, I2C 0x40) ──────────────────────────────────
    float inaVoltage;    // bus voltage, V  (set to supplyVoltage constant)
    float inaCurrent;    // current, A
    float inaPower;      // computed power, W  (= inaVoltage × inaCurrent)
    bool  inaOk;         // false if INA226 not found on I2C at boot

    // ── EZO-HUM humidity probe (I2C 0x6F) ─────────────────────────────────
    float humidityPct;   // relative humidity, %RH  (0 if sensor absent)
    float humTemp;       // ambient temperature from probe, °C
    bool  ezoHumOk;      // false if no valid response received yet

    // ── Differential pressure sensor (SDP510, I2C 0x40) ──────────────────────
    // Ch1: SDP510 via I2C (SDA=GPIO15, SCL=GPIO16) | Ch2: unused (always 0)
    // Range: ±500 Pa, scale factor 60 counts/Pa, factory calibrated
    float deltaP1Raw;    // channel 1, Pa — direct SDP610 reading
    float deltaP1Filt;   // channel 1, Pa — EMA filtered (α=0.15)
    float deltaP2Raw;    // channel 2, Pa — always 0.0 (no second sensor)
    float deltaP2Filt;   // channel 2, Pa — always 0.0 (no second sensor)

    // ── Status flags ───────────────────────────────────────────────────────
    bool  tempStuck;     // true this tick if stuck-watchdog fired (heater cut)
};

// ── SensorManager ──────────────────────────────────────────────────────────────
// Owns all sensor objects, signal conditioning, and health detection.
// Call begin() once in setup(), then read() once per control tick.
class SensorManager {
public:
    // Initialise I2C, INA226, and set initial EMA alpha.
    // MAX6675 is initialised via its constructor (no extra begin needed).
    void begin(float emaAlphaInit);

    // Update EMA smoothing coefficient (called when SET ALPHA is received).
    void setEmaAlpha(float alpha);

    // Read all sensors and return a snapshot for this tick.
    // Safe to call even if a sensor is absent — absent fields return 0 or NAN.
    CoreSensorData read();

    // Reset EMA state (e.g. on mode change or RUN OFF → ON).
    void resetEma();

    // Reset stuck-sensor watchdog counters.
    void resetStuck();
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

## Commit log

2026-02-25 made it possible to edit the PID controls and also it in a GUI
2026-03-02 added a Fan and made the speed variable via the GUI
    [Schamtic and PCB Girona heatmeasuement.kicad_pcb, Schamtic and PCB Girona heatmeasuement.kicad_sch]
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2026-03-03 feat(control): add SMART PWM hold mode with visible handover/fallback progress
    - Add control modes AUTO/MANUAL/SMART with persisted mode and manual PWM
    - Implement SMART supervisor: PID -> learned constant HOLD PWM -> auto fallback to PID on drift
    - Add fractional PWM dithering for non-integer hold/manual PWM targets
    - Improve SMART stability logic with noise-tolerant decay counter and tuned thresholds
    - Make SMART thresholds thermocouple-accuracy aware (0.25 C based bands)
    - Emit telemetry for MODE/STATE/MANPWM/HOLDPWM and ENTPROG/EXTPROG/EABS
    - Add explicit serial transition logs for SMART enter/exit hold
    - Extend GUI with mode controls, manual PWM controls, and SMART live fields
    - Add plo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
    [Schamtic and PCB Girona heatmeasuement.kicad_sch]
2026-03-03 feat(gui): add integrated CSV logging plus runtime control/smart tuning controls
    - Add Start/Stop CSV logging directly in pid_gui (single serial connection)
    - Write parsed live telemetry to logs/serial_YYYYMMDD_HHMMSS.csv with extended fields
    - Auto-stop and flush CSV logging on disconnect/close
    - Add heater run control commands (SET RUN ON/OFF) and GUI Start/Stop buttons
    - Add fan PWM inversion support (SET FANINV) with GUI checkbox/apply action
    - Extend firmware telemetry/config with RUN and FANINV status
    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
2026-03-03 feat: add SMART PID lab workflow improvements, integrated GUI CSV logging, runtime RUN/FANINV controls, and enhanced plotting/slider UX
2026-03-03 docs(planning): add prioritized roadmap framework and upgrade-proof CSV schema v2
    - Add scoring model to notes/Ideas.md:
    - Importance, Necessity, Dependency, Effort
    - formula: Score = 2*Importance + 2*Necessity + 2*Dependency - Effort
    - Add reusable backlog item template with acceptance criteria fields
    - Add phased roadmap (P0/P1/P2) aligned to heatsink testing, power sensor, and airflow sensors
    - Update tools/README.md with CSV Schema v2 guidance:
    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
2026-03-18 fix: correct pin assignments and migrate to ESP32 Arduino core v3 PWM API
    - Fan PWM pin corrected from 8 to 5 to match hardware wiring
    - Thermocouple pins shifted by one (SCK 12→13, CS 11→12, SO 10→11)
    - Replace deprecated ledcSetup/ledcAttachPin/ledcWrite(channel) with
    ledcAttach(pin) and ledcWrite(pin) for ESP32 Arduino core v3 compatibility
    [main.cpp]
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2026-03-18 feat: add INA226 current/power monitoring and fix PWM pin assignments
    - Add INA226 current sensor support (I2C, 0x40) with calibrated shunt (0.038Ω)
    - Add 1024-sample averaging for accurate PWM duty-cycle current measurement
    - Fix heaterMosfetPin to pin 4, fanPwmPin to pin 5
    - Add I2C pins (SDA=15, SCL=16)
    - Use fixed supply voltage (12V) for power calculation
    - Report current (A), voltage (V), and power (W) in telemetry
    [main.cpp]
2026-03-18 feat: add web-based GUI and fix serial connect/disconnect ESP32 reset
    - Add tools/web_gui/ with FastAPI+WebSocket backend and single-file HTML frontend
    - Replaces tkinter pid_gui.py with browser-based interface (no extra installs)
    - Live chart (Chart.js), all PID controls, telemetry, CSV logging, serial log
    - Resizable serial log panel with color-coded lines and timestamps
    - Fix ESP32-S3 reset on serial connect/disconnect by holding DTR/RTS low
    - Update platformio.ini
    [pid_gui_state.json]
2026-03-18 fix: resolve connect/disconnect bugs in web GUI serial handling
    - Broadcast 'connected' event to UI after successful serial connect
    - Run serial open() in executor with 5s timeout to prevent server freeze
    - Auto-disconnect and broadcast 'disconnected' on handshake failure
    - Properly close serial port on handshake fail from reader thread
    - Remove blocking reader_thread.join() from connect path
    [server.py]
2026-03-19 fix: separate chart controls from chart box, fix scrollable layout
    - Move series checkboxes and chart controls into separate .chart-settings bar above chart
    - Chart box now contains only the canvas
    - Chart area uses fixed height (420px) so content overflows and page scrolls
    - Add chart resize handle at bottom edge to drag chart taller
    - Log resize handle min-height raised to 130px (~4 lines)
    - Default series selection: Smooth, SP, PWM only (remove Raw Temp and Temp)
2026-03-19 feat: add virtual MCU simulator with physics tuning and fast-forward
    - Add VirtualMCU class: simulates ESP32 heater controller (PID, SMART mode, thermal physics)
    - Physics calibrated from real CSV: 0.24°C/s at full PWM, reaches 60°C in ~163s
    - VIRTUAL port appears at top of port dropdown, no hardware needed
    - Fast-forward buttons: 1×/5×/10×/20×/50× realtime speed
    - Editable physics params in UI: heater power, thermal mass, cooling coeff, ambient temp
    - All SET/GET serial commands work against the simulator
    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
2026-03-19 feat: add equilibrium PWM tracker and live heatsink characterization
    Firmware (src/main.cpp):
    - Add eqPwm global: EMA that converges toward thermal balance PWM
    - Only updates when absSlope < 0.3°C/s (temperature near stable)
    - Appended EQPWM field to telemetry Serial.printf line
    Server (server.py):
    - Extend TELEMETRY_RE to parse V/I/W (INA226) and EQPWM fields
    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
2026-03-19 feat: tester mode, Power W series, checkbox fixes, CSV download, manual
    - Fix Raw Temp/Temp checkbox inversion (add hidden:true to SERIES_CFG)
    - Add Power W chart series and telemetry display
    - Hide P/I/D/PID series behind PID Debug toggle
    - Add Tester Mode: automated multi-setpoint test with soak/convergence logic
    - Tester mode exports Results CSV and Raw CSV
    - Add /api/csv/download endpoint to server.py
    - Add MANUAL.md installation and usage guide
    [server.py]
2026-03-19 feat: tester mode, PID debug toggle, power series, start.bat, manual, serial fix
2026-03-19 feat: add start.bat for Windows quick-start and update MANUAL.md
    - Add tools/web_gui/start.bat (installs deps + launches server.py)
    - Update MANUAL.md to reference start.bat for Windows and pip install -r requirements.txt
    - Add start.bat to publish.bat so it syncs to the public repo
    [pid_gui_state.json]
2026-03-29 docs: add CLAUDE.md and rewrite Ideas.md for agent-mode readiness
    - Add CLAUDE.md with full project context for Claude agent mode: end goal
    (one-button student workflow), software-first philosophy, architecture,
    serial protocol, telemetry format, future sensor extensibility pattern,
    safety rules, code conventions, and scored feature backlog
    - Rewrite notes/Ideas.md with accurate scoring, 9 new backlog items aligned
    to the student-facing end goal (auto shutdown, range entry, guided wizard,
    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
2026-03-29 feat: add phase markers, presets, CSV column picker, expert/student mode, performance metrics, graph cursor, and Excel import guide
    - Phase markers: stamp current moment with a label; writes event row to CSV and draws orange dashed line on chart
    - Presets: save/load/delete named configs stored in presets.json; three built-in presets included
    - CSV column customization: modal dialog to select columns before recording; generates Power Query M formula with comment-line filtering
    - Excel import help: step-by-step guide (8 screenshots) that slides out from the CSV dialog as a side panel
    - Expert/Student mode toggle: hides advanced PID params and telemetry fields; state persisted across sessions
    -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
2026-04-07 refactor: split firmware into modular files + extensible sensor registry (#8)
    - Extract SensorManager (MAX6675, INA226, EMA, glitch reject, stuck watchdog)
    - Extract SerialProtocol (handleCommand, printConfig, emitTelemetry, NVS)
    - Add ExtSensorRegistry: fixed 8-slot registry so future sensors auto-append
    to telemetry with registerSensor()/update() — no format string edits needed
    - Add SystemState.h: POD struct centralising all config and runtime state
    - Slim main.cpp to setup, loop, control FSM, and actuators (~230 lines)
    - Telemetry format byte-for-byte identical; server.py requires zero changes
    - Build verified clean: pio run SUCCESS (9.8% flash, 6.1% RAM)
    - Update CLAUDE.md key files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
    [SensorManager.cpp, SensorManager.h, SerialProtocol.cpp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]
2026-04-17 feat: add Atlas Scientific EZO-HUM humidity sensor integration (#9)
    Adds full support for the EZO-HUM™ Embedded Humidity Probe (I2C, 0x6F)
    sharing the existing I2C bus with the INA226 on GPIO 15/16.
    Firmware:
    - SensorManager owns all EZO-HUM I2C interaction (init, non-blocking
    read/send cycle, status-byte parsing). CoreSensorData gains
    humidityPct, humTemp, ezoHumOk fields.
    - main.cpp is kept clean: registers two ExtSensorRegistry slots and
    updates them from sd.humidityPct / sd.humTemp each tick.
    - Fixes Atlas EZO I2C status-byte protocol (first byte = 0x01 success;
    skipping it was causing humidity to always read 0.0%).
    Backend:
    - TELEM_RE extended with HUMIDITY and HUM_TEMP capt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
    [SensorManager.cpp, SensorManager.h, main.cpp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]
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2026-05-11 Fix pressure sensor issues: replace SDP2000-L analog with SDP510 I2C (#11 #12)
    - Replace SDP2000-L analog sensor with SDP510 I2C (address 0x40)
    - Fix INA226 address 0x40 → 0x41 (A0 wired to VCC)
    - Add Wire.setTimeOut(200) for SDP510 clock stretching (fixes Error 263)
    - Add SDP510 startup diagnostic with first reading printout
    - Remove SDP2000-L software correction (SDP510 is factory calibrated)
    - Fix PC lag: concurrent WebSocket broadcast + requestAnimationFrame throttle
    - Add software pressure tare (Zero ΔP / Reset Zero buttons)
    https://claude.ai/code/session_01G3oTXKVrqRuThGQecP4rHF
    [SensorManager.cpp, SensorManager.h, server.py]
2026-05-13 fix: ESP connection hangs forever at "Connecting..." on new PC (#14)
    * fix: handshake timeout never fires when ESP sends no data
    The reader loop's `if not line: continue` guard caused the handshake
    deadline check to be skipped entirely on empty reads (0.2s serial
    timeout). On PCs where the USB-serial driver pulses DTR on port-open,
    the ESP32 resets and takes a few seconds to boot — during which it
    sends nothing. The GUI would hang at "Connecting..." indefinitely with
    no error.
    Fix: restructure the loop so the deadline check runs on every
    iteration regardless of whether a line was received. Also extend the
    handshake window from 2.5s to 5.0s to cover ESP boot time after reset.
    https://cla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
    [server.py]
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2026-05-25 chore: repo cleanup — remove schematic, fix gitignore, fix publish.bat (#18)
    * chore: repo cleanup — remove schematic folder, fix gitignore, fix publish.bat
    - Remove KiCad schematic folder (no longer needed)
    - Remove tracked runtime/cache files: pid_gui_state.json, __pycache__/*.pyc, .claude/worktrees/
    - Fix .gitignore: correct pid_gui_state.json path, add __pycache__/, *.pyc, .claude/
    - Fix publish.bat: add missing src/ firmware files (SensorManager, SerialProtocol,
    ExtSensorRegistry, SystemState), student.html, and static/media/ images
    https://claude.ai/code/session_01S75npJi7EvrXo5LYNiYW5e
    * chore: remove superseded standalone tools
    pid_gui.py, serial_to_csv.py, and i2c_scanner/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
    [Schamtic and PCB Girona heatmeasuement.kicad_pcb, Schamtic and PCB Girona heatmeasuement.kicad_sch, pid_gui_state.json]
2026-05-26 MOSFET fan power control + fan-off test option + ambient temp auto-fill
    * Add MOSFET fan power control on GPIO 10 (issue #16)
    Adds SET FANPWR ON/OFF command to firmware, backend, and GUI so the
    fan can be completely cut via a MOSFET gate (GPIO 10), giving true
    zero airflow independent of PWM speed.
    - PIN_FAN_POWER = 10, sys.fanPowerEnabled flag in SystemState
    - applyFanPower() helper writes HIGH/LOW to GPIO 10
    - SET FANPWR command with NVS persistence
    - FANPWR field added to telemetry and CFG lines
    Backend (server.py):
    - TELEMETRY_RE: FANPWR captured as group 28; HUMIDITY–DELTA groups
    shifted to 29–34 accordingly
    - CFG_RE: optional FANPWR group 16 for backward compa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
    [SerialProtocol.cpp, main.cpp, server.py]
2026-05-26 Fix SMART HOLD stuck on SP change; per-temp test order; humidity CSV export
    - Fix SMART HOLD not exiting when setpoint or fan changes (force SET MODE AUTO → SMART to reset state machine regardless of EXITCNT in NVS)
    - Fix race condition: expectedSP + settling guards prevent carry-over enter_prog=100 from triggering premature soak
    - Reorder test loop: outer=temperature, inner=fan speeds — heats up once per temp, sweeps all fans, avoids cool-down cycles
    - Set SP and first fan before SET RUN ON to prevent heating against stale NVS setpoint
    - Fix humidity_pct and hum_temp_c missing from CSV writerow in server.py
    [server.py]
2026-05-26 docs: complete documentation overhaul for thesis submission
    - README.md: rewrite with corrected hardware table (INA226 addr 0x41,
    SDP510 at 0x40, EZO-HUM at 0x6F), full pin assignment table, all
    wiring sections (heater/fan power paths, each sensor), system
    architecture diagram, serial command reference, telemetry field list,
    CSV schema, and repo structure
    - docs/hardware.md: new detailed hardware reference — BOM, ESP32 pin
    table, I2C bus map with address conflict notes, power distribution
    diagrams, per-sensor wiring tables, physical assembly descriptions
    keyed to media photos, safety notes, and planned sensor additions
    - tools/web_gui/MANUAL.md: update for port 8765 (was 8000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
2026-05-26 chore: pre-publication safety fixes
    - Strip GPS EXIF coordinates from all 18 docs/media/*.HEIC photos
    - Add MIT LICENSE file
    - Remove .claude/settings.local.json from git tracking (IDE scaffolding)
    - Remove docs/wiring_schematic.docx from git tracking (regenerable artifact)
    - Remove tools/web_gui/static.zip (orphaned, unreferenced binary)
    - Fix hardcoded Windows path in docs/generate_wiring_schematic.py (exposed
    local username + OneDrive path); replaced with relative os.path reference
    - Update .gitignore: add *.env, presets.json, wiring_schematic.docx
    https://claude.ai/code/session_014SPygZLPF8qcmPDG6X5RFq
    [generate_wiring_schematic.py]
2026-05-28 Fix GUI on air-gapped Windows PCs (Python 3.14 compatible)
    - Bundle Chart.js locally so the GUI works without internet access
    - Bundle all Python wheels for offline pip install (Python 3.12/3.13/3.14)
    - Fix start.bat syntax error on non-English Windows (goto instead of if-blocks)
    - Fix asyncio.Lock() crashing WebSocket handler silently on Python 3.14
    - Fix ClearCommError treated as fatal on incompatible USB-serial adapters
    - Fix asyncio.get_event_loop() → get_running_loop() for Python 3.14
    [server.py]
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2026-05-30 Add KiCad 8 carrier board project (schematic + PCB layout)
    Includes .kicad_pro, .kicad_sch, and .kicad_pcb for the 160x120mm
    3D-printable ESP32-S3 carrier board with JST-XH connectors for all
    sensors, IRLZ44N MOSFETs for heater/fan, INA226, I2C pull-ups, and
    MOSFET gate pull-downs.
    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
    [heatsinklab.kicad_pcb, heatsinklab.kicad_sch]
2026-05-30 Fix KiCad schematic/PCB: remove invalid ;; comments, update to v9 format
    KiCad s-expression format has no comment syntax — ;; lines caused a
    parse error on load. Also bumped version to 20240101 / generator 9.0.
    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
    [heatsinklab.kicad_pcb, heatsinklab.kicad_sch]
2026-05-30 Rewrite KiCad schematic with correct KiCad 9 s-expression syntax
    Fix net_label->label, remove invalid property inside labels, fix
    fields_autoplaced, use proper UUIDs, correct all symbol definitions.
    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
    [heatsinklab.kicad_sch]
2026-05-30 Update PCB: proper ESP32-S3-DevKitC-1 2x22 pin footprint with correct GPIO net assignments
    Replace old 13-pin placeholder with two 22-pin headers matching the
    DevKitC-1 pinout. Left header: 3V3(L1-2), GPIO4(L4), GPIO5(L5),
    GPIO15/SDA(L8), GPIO16/SCL(L9), GPIO10(L16), GPIO11/MISO(L17),
    GPIO12/CS(L18), GPIO13/SCK(L19), GND(L22). Right header: GND(R1,R21-22).
    Row spacing 22.86mm matching physical board.
    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
    [heatsinklab.kicad_pcb]
2026-05-30 Merge FAN_OUT + FAN_PWM into single 3-pin JST-XH connector J4
    J4 now carries: pin1=12V(via Q2), pin2=GND, pin3=GPIO5_PWM.
    Removes separate J5 2-pin connector. Adds Conn_01x03 lib symbol.
    Updates PCB footprint to JST_XH_B3B-XH-A and wiring schematic doc.
    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
    [heatsinklab.kicad_pcb, heatsinklab.kicad_sch]
